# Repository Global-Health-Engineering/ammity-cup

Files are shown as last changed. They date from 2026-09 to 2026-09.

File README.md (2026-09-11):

<!-- badges: start -->



<!-- badges: end -->

<br>
<p align="middle">
Global Health Engineering, ETH Zurich
</p>

# SpaceCup (AMMITY)

- **Kim Keller** (ETH Zürich, Global Health Engineering) *design, construction, testing, writing*
- **Marion Dugué** (ETH Zürich, Global Health Engineering) *flight-experiment co-lead, supervision*
- **Jakub Tkaczuk** [ORCID 0000-0001-7997-9423](https://orcid.org/0000-0001-7997-9423) (ETH Zürich, Global Health Engineering) *supervision, page development & maintenance*
- **Elizabeth Tilley** [ORCID 0000-0002-2095-9724](https://orcid.org/0000-0002-2095-9724) (ETH Zürich, Global Health Engineering) *supervision*

**SpaceCup (AMMITY) is an open-source, cast-silicone menstrual cup that seals before extraction, designed for menstruation in reduced gravity.** Seven closing mechanisms were designed on a shared base cup geometry; six were scored in a 1 G bench test, with Flower Low and Flower High scoring highest at 24 out of 25, and Flower Low, the only fully functional prototype available at the time, was flown during the Asclepios VI parabolic-flight campaign. SpaceCup is a research prototype, bench-tested and flown for short reduced-gravity windows, not a certified medical device.

**Full site, with renders, 3D models and documentation, is available [here](https://global-health-engineering.github.io/ammity-cup/).**

## At a glance

| Characteristic | Description |
| --- | --- |
| Mechanisms designed | 7: Flower Low, Flower High, Twister, Umbrella, Duckbill, Drawstring, Balloon |
| Mechanisms bench-scored | 6 (Balloon excluded, not reliably manufacturable) |
| Best bench score | Flower Low and Flower High, 24/25 |
| Flown | Flower Low, Asclepios VI parabolic-flight campaign |
| Manufacture | Cast silicone in 3D-printed moulds |
| CAD | Siemens NX source, shipped as STEP |
| Status | Research prototype |

## Quick start

1. Pick a variant in [`hardware/README.md`](hardware/README.md).
2. Print its `mould-stl/`.
3. Cast, following [`docs/manufacturing.md`](docs/manufacturing.md).
4. Use and clean, following [`docs/use.md`](docs/use.md).

## Repository layout

```
hardware/              CERN-OHL-P v2: the cup and mould geometry
├── README.md          Variant table, file map, rename map
├── nx.md              Siemens NX source CAD and the STEP editable format
├── flower-low/         Flown mechanism (step/, stl/, mould-stl/)
├── flower-high/        Bench-tested Flower variant
├── twister/             Bench-tested mechanism
├── umbrella/            Bench-tested mechanism
├── duckbill/            Bench-tested mechanism
├── drawstring/          Bench-tested mechanism
├── balloon/             Not reliably manufacturable, not scored
├── extraction-valve/    Untested concept, outside the bench-tested set
└── artificial-vagina/   Test equipment, not a cup design

docs/                  CC BY 4.0: design, manufacturing, use and validation
├── design.md           Base geometry, the seven mechanisms, bench scoring
├── manufacturing.md    Mould printing and silicone casting
├── use.md              Insertion, activation, extraction, cleaning
├── validation.md       Bench-test and parabolic-flight results
├── flight-protocol.md  The Asclepios VI flight test procedure
├── design-history.md   Where the base geometry and mechanisms came from
└── moulding-guide.pdf  The original injection-moulding guide

data/                  CC BY 4.0: bench, cleaning and flight-questionnaire data
tools/                 CC BY 4.0: scripts that regenerate every render and gate CI
site/                  CC BY 4.0: this repository's GitHub Pages site (Astro)
CITATION.cff           Machine-readable citation metadata
```

## Citation

If you use this hardware, please cite it; see [`CITATION.cff`](CITATION.cff) for the machine-readable record:

> SpaceCup (AMMITY): an open-source menstrual cup that seals before
> extraction, for menstruation in reduced gravity. Kim Keller, Marion
> Dugué, Jakub Tkaczuk, Elizabeth Tilley. ETH Zurich, Global Health
> Engineering. Version 1.0.0. https://github.com/Global-Health-Engineering/ammity-cup

## License

Different parts of this repository are released under different licenses, following standard practice for open-hardware projects:

| Component | License |
| --- | --- |
| Hardware design (STEP, whole-part STL, mould STL in [`hardware/`](hardware/)) | [CERN-OHL-P v2](LICENSE-CERN-OHL-P-2.0.md) |
| Documentation, data, site and tooling | [CC BY 4.0](LICENSE-CC-BY-4.0.md) |

## Acknowledgements

The parabolic-flight experiments were flown by the analogue astronauts of the Asclepios VI mission. Medical-grade silicone was donated by WACKER Chemie AG. Medical input was provided by Dr. Cornelia Betschart. The team also thanks CNES for sharing their expertise in human spaceflight and space medicine.

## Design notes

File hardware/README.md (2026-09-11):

# hardware

Licensed **CERN-OHL-P v2** (see `../LICENSE-CERN-OHL-P-2.0.md`).

## Variants

| Variant | Mechanism | Status | Bench score | Folder |
|---|---|---|---|---|
| flower-low | Five flexible petals, each joined by a silicone string to a pull mechanism in the stem, that close together to seal the opening (thesis p.10) | flown (Asclepios VI) | 24/25 | [`flower-low/`](flower-low/) |
| flower-high | The same petal-and-string mechanism as Flower Low, with the petals' base moved closer to the rim for further reach against fluid pooled above the cup (thesis p.10) | bench-tested | 24/25 | [`flower-high/`](flower-high/) |
| twister | A thin membrane skin that forms a hyperboloid seal when the cup's bottom part is rotated against the top (thesis p.10) | bench-tested | 21/25 | [`twister/`](twister/) |
| umbrella | An inverted-umbrella structure that expands into a seal when a central element is pulled downward (thesis p.10) | bench-tested | 16/25 | [`umbrella/`](umbrella/) |
| balloon | An inflatable membrane on the cup wall that rotates upward to seal the opening when a stem-integrated balloon is compressed (thesis p.10) | not reliably manufacturable | not scored (excluded, thesis p.20) | [`balloon/`](balloon/) |
| duckbill | A pressure-difference valve between an upper and lower chamber, opened by squeezing the cup before removal (thesis p.10) | bench-tested | 22/25 | [`duckbill/`](duckbill/) |
| drawstring | A flexible lid, folded against the inner wall, drawn across the opening by a stem-integrated pull string (thesis p.10) | bench-tested | 18/25 | [`drawstring/`](drawstring/) |
| extraction-valve | A valve-and-button assembly intended to withdraw fluid through a port while the cup stays inserted; an eighth, later concept, not one of the thesis's seven mechanisms and not tested or described in the thesis (see [`../docs/design.md`](../docs/design.md)) | untested concept | not scored | [`extraction-valve/`](extraction-valve/) |
| artificial-vagina | Two test models: the self-made model here, cast from the printed mould, was used for the 1 G bench tests (thesis pp.14-15); the flights used a separate, store-bought model, not shipped in this repository (thesis p.17). The file names ("parabolicflight_vagina") are the author's own and predate the flight/bench distinction | test equipment | not applicable | [`artificial-vagina/`](artificial-vagina/) |

Bench scores are the `overall` column of [`../data/ground-test-scores.csv`](../data/ground-test-scores.csv) (out of 25); see [`../docs/design.md`](../docs/design.md) for the full breakdown by criterion.

## What is in each folder

- `step/` holds the cup and mould B-rep, editable.
- `stl/` holds the whole cup and whole mould as single meshes, for viewing; print from `mould-stl/`, which holds the split, print-ready pieces.
- `mould-stl/` holds the print-ready mould pieces, split for printing.

## Which files are the cup and which are the mould

STEP files with `mould` in the name are moulds. The rest are the cast parts. Some cast parts are modelled as halves rather than a single closed solid: `umbrella/menstrual-cup-medium-without-umbrella.step` and `duckbill/duckbill-half-withrim.step`.

## Known gaps

- The balloon membrane exists only as a mould (`balloon-top-mould.step`); the balloon part itself could not be manufactured reliably and was excluded from bench testing (thesis p.20). The concept render shows the balloon derived from that mould's cavity, with the vent and core-pin channels trimmed (`tools/render_parts.py`, `derive_mould_cavity`), not from a part file.
- The drawstring lid is modelled flat, as moulded, not folded against the inner wall as it sits in the cup. The concept render shows it that way: flat, beside the cup.
- `flower-high/step/flower-cup-withrim-higher.step` is one fused solid (cup, petal disc, petals and strings together). The renders colour its petals and strings by a geometric rule calibrated on Flower Low's separate solids (`tools/parts.py`, `FaceSplit`), not by solids in the file.
- `flower-low/step/flower-cup-withrim-part.step` holds 6 solids: two cup-body halves split at the mould parting plane, two small pieces at the stem end, a petal disc, and the petals-with-strings solid.
- `flower-low` also contains a `flower-stopper` (`flower-stopper.step`, `flower-stopper-mould.step`), which the thesis does not describe.
- The extraction valve is an eighth, later concept: it is not one of the thesis's seven designed mechanisms, was not tested, and is not described in the thesis; it has no bench-test or flight data.
- In the Flower Low and Flower High CAD, the pull strings are modelled straight, as cast (the mould cores run to the same length). In the cast cup, each petal's string joins the pull mechanism in the stem (thesis p.10). The renders show this as-cast, straight-string geometry, not the strings pulled taut.
- The drawstring's pull-string tabs are small and sit inside the rim, so they are barely visible in the render.

## Printing the moulds

The moulds print in ASA when the silicone needs a heated, 100 °C cure (medical-grade ELASTOSIL), or in PLA, PETG or ABS for room-temperature-cured silicones such as Smooth-Sil and Rebound. See [`../docs/manufacturing.md`](../docs/manufacturing.md) for material selection, mould features, mixing, injection, curing times and known defects.

## Units

Every STL and STEP file here is in millimetres, checked in CI:

```bash
python3 tools/verify_units.py "hardware/*/mould-stl/*.stl" "hardware/*/stl/*.stl"
```

STEP files declare `SI_UNIT(.MILLI.,.METRE.)` and need no conversion.

## Rename map

The thesis uses the author's original names. This repository renames every shipped file to a consistent, lower-case, hyphenated scheme. The table below is the full old to new mapping.

| Original name (thesis, CAD export) | In this repository |
|---|---|
| `Flower Low Cup/Print Flower/flower_cup_withrim_mold_bottomleft_m.stl` | `flower-low/mould-stl/flower-cup-withrim-mould-bottomleft.stl` |
| `Flower Low Cup/Print Flower/flower_cup_withrim_mold_bottomright_m.stl` | `flower-low/mould-stl/flower-cup-withrim-mould-bottomright.stl` |
| `Flower Low Cup/Print Flower/flower_cup_withrim_mold_middleleft_m.stl` | `flower-low/mould-stl/flower-cup-withrim-mould-middleleft.stl` |
| `Flower Low Cup/Print Flower/flower_cup_withrim_mold_middleright_m.stl` | `flower-low/mould-stl/flower-cup-withrim-mould-middleright.stl` |
| `Flower Low Cup/Print Flower/flower_cup_withrim_mold_topleft_m.stl` | `flower-low/mould-stl/flower-cup-withrim-mould-topleft.stl` |
| `Flower Low Cup/Print Flower/flower_cup_withrim_mold_topright_m.stl` | `flower-low/mould-stl/flower-cup-withrim-mould-topright.stl` |
| `Flower Low Cup/Print Flower/flower_stopper_mold_bottom_m.stl` | `flower-low/mould-stl/flower-stopper-mould-bottom.stl` |
| `Flower Low Cup/Print Flower/flower_stopper_mold_top_m.stl` | `flower-low/mould-stl/flower-stopper-mould-top.stl` |
| `Flower Low Cup/Step files/flower_cup_withrim_mold_m.stp` | `flower-low/step/flower-cup-withrim-mould.step` |
| `Flower Low Cup/Step files/flower_cup_withrim_part_m.stp` | `flower-low/step/flower-cup-withrim-part.step` |
| `Flower Low Cup/Step files/flower_stopper_m.stp` | `flower-low/step/flower-stopper.step` |
| `Flower Low Cup/Step files/flower_stopper_mold_m.stp` | `flower-low/step/flower-stopper-mould.step` |
| `Flower Low Cup/Stl files/flower_cup_withrim_mold_m.stl` | `flower-low/stl/flower-cup-withrim-mould.stl` |
| `Flower Low Cup/Stl files/flower_cup_withrim_part_m.stl` | `flower-low/stl/flower-cup-withrim-part.stl` |
| `Flower Low Cup/Stl files/flower_stopper_m.stl` | `flower-low/stl/flower-stopper.stl` |
| `Flower Low Cup/Stl files/flower_stopper_mold_m.stl` | `flower-low/stl/flower-stopper-mould.stl` |
| `Flower High Cup/Print Flower high/flower_cup_withrim_higher_mold_inleft.stl` | `flower-high/mould-stl/flower-cup-withrim-higher-mould-inleft.stl` |
| `Flower High Cup/Print Flower high/flower_cup_withrim_higher_mold_inright.stl` | `flower-high/mould-stl/flower-cup-withrim-higher-mould-inright.stl` |
| `Flower High Cup/Print Flower high/flower_cup_withrim_higher_mold_outbottomleft.stl` | `flower-high/mould-stl/flower-cup-withrim-higher-mould-outbottomleft.stl` |
| `Flower High Cup/Print Flower high/flower_cup_withrim_higher_mold_outbottomright.stl` | `flower-high/mould-stl/flower-cup-withrim-higher-mould-outbottomright.stl` |
| `Flower High Cup/Print Flower high/flower_cup_withrim_higher_mold_outtopleft.stl` | `flower-high/mould-stl/flower-cup-withrim-higher-mould-outtopleft.stl` |
| `Flower High Cup/Print Flower high/flower_cup_withrim_higher_mold_outtopright.stl` | `flower-high/mould-stl/flower-cup-withrim-higher-mould-outtopright.stl` |
| `Flower High Cup/Step files/flower_cup_withrim_higher_m.stp` | `flower-high/step/flower-cup-withrim-higher.step` |
| `Flower High Cup/Step files/flower_cup_withrim_higher_mold_m.stp` | `flower-high/step/flower-cup-withrim-higher-mould.step` |
| `Flower High Cup/Stl files/flower_cup_withrim_higher_m.stl` | `flower-high/stl/flower-cup-withrim-higher.stl` |
| `Flower High Cup/Stl files/flower_cup_withrim_higher_mold_m.stl` | `flower-high/stl/flower-cup-withrim-higher-mould.stl` |
| `Twister Cup/Print Twister/Twister_Cup_Top2_bottom.stl` | `twister/mould-stl/twister-cup-top2-bottom.stl` |
| `Twister Cup/Print Twister/Twister_Cup_Top2_middle.stl` | `twister/mould-stl/twister-cup-top2-middle.stl` |
| `Twister Cup/Print Twister/Twister_Cup_Top2_middleoutside.stl` | `twister/mould-stl/twister-cup-top2-middleoutside.stl` |
| `Twister Cup/Print Twister/Twister_Cup_Top2_top.stl` | `twister/mould-stl/twister-cup-top2-top.stl` |
| `Twister Cup/Print Twister/twister_cup_bottom_3_withdent_inleft.stl` | `twister/mould-stl/twister-cup-bottom-3-withdent-inleft.stl` |
| `Twister Cup/Print Twister/twister_cup_bottom_3_withdent_inright.stl` | `twister/mould-stl/twister-cup-bottom-3-withdent-inright.stl` |
| `Twister Cup/Print Twister/twister_cup_bottom_3_withdent_outleft.stl` | `twister/mould-stl/twister-cup-bottom-3-withdent-outleft.stl` |
| `Twister Cup/Print Twister/twister_cup_bottom_3_withdent_outright.stl` | `twister/mould-stl/twister-cup-bottom-3-withdent-outright.stl` |
| `Twister Cup/Print Twister/twister_skin_mold_1.stl` | `twister/mould-stl/twister-skin-mould-1.stl` |
| `Twister Cup/Print Twister/twister_skin_mold_2.stl` | `twister/mould-stl/twister-skin-mould-2.stl` |
| `Twister Cup/Print Twister/twister_skin_mold_3.stl` | `twister/mould-stl/twister-skin-mould-3.stl` |
| `Twister Cup/Print Twister/twister_skin_mold_4.stl` | `twister/mould-stl/twister-skin-mould-4.stl` |
| `Twister Cup/Print Twister/twister_skin_mold_5.stl` | `twister/mould-stl/twister-skin-mould-5.stl` |
| `Twister Cup/Print Twister/twister_skin_mold_6.stl` | `twister/mould-stl/twister-skin-mould-6.stl` |
| `Twister Cup/Print Twister/twister_skin_mold_insideleft.stl` | `twister/mould-stl/twister-skin-mould-insideleft.stl` |
| `Twister Cup/Print Twister/twister_skin_mold_insideright.stl` | `twister/mould-stl/twister-skin-mould-insideright.stl` |
| `Twister Cup/Step files/Twister_Cup_Top_m.stp` | `twister/step/twister-cup-top.step` |
| `Twister Cup/Step files/Twister_Cup_Top_mold.stp` | `twister/step/twister-cup-top-mould.step` |
| `Twister Cup/Step files/twister_cup_bottom_withdent.stp` | `twister/step/twister-cup-bottom-withdent.step` |
| `Twister Cup/Step files/twister_cup_bottom_withdent_mold.stp` | `twister/step/twister-cup-bottom-withdent-mould.step` |
| `Twister Cup/Step files/twister_skin.stp` | `twister/step/twister-skin.step` |
| `Twister Cup/Step files/twister_skin_mold.stp` | `twister/step/twister-skin-mould.step` |
| `Twister Cup/Stl files/Twister_Cup_Top_m.stl` | `twister/stl/twister-cup-top.stl` |
| `Twister Cup/Stl files/Twister_Cup_Top_mold.stl` | `twister/stl/twister-cup-top-mould.stl` |
| `Twister Cup/Stl files/twister_cup_bottom_withdent.stl` | `twister/stl/twister-cup-bottom-withdent.stl` |
| `Twister Cup/Stl files/twister_cup_bottom_withdent_mold.stl` | `twister/stl/twister-cup-bottom-withdent-mould.stl` |
| `Twister Cup/Stl files/twister_skin.stl` | `twister/stl/twister-skin.stl` |
| `Twister Cup/Stl files/twister_skin_mold.stl` | `twister/stl/twister-skin-mould.stl` |
| `Umbrella Cup/Print Umbrella/menstrual_cup_medium_without_umbrella_mold_insideleft.stl` | `umbrella/mould-stl/menstrual-cup-medium-without-umbrella-mould-insideleft.stl` |
| `Umbrella Cup/Print Umbrella/menstrual_cup_medium_without_umbrella_mold_insideright.stl` | `umbrella/mould-stl/menstrual-cup-medium-without-umbrella-mould-insideright.stl` |
| `Umbrella Cup/Print Umbrella/menstrual_cup_medium_without_umbrella_mold_outsideleft_m.stl` | `umbrella/mould-stl/menstrual-cup-medium-without-umbrella-mould-outsideleft.stl` |
| `Umbrella Cup/Print Umbrella/menstrual_cup_medium_without_umbrella_mold_outsideright_m.stl` | `umbrella/mould-stl/menstrual-cup-medium-without-umbrella-mould-outsideright.stl` |
| `Umbrella Cup/Print Umbrella/umbrella_contain_silicone_mold_inside.stl` | `umbrella/mould-stl/umbrella-contain-silicone-mould-inside.stl` |
| `Umbrella Cup/Print Umbrella/umbrella_contain_silicone_mold_outsideleft.stl` | `umbrella/mould-stl/umbrella-contain-silicone-mould-outsideleft.stl` |
| `Umbrella Cup/Print Umbrella/umbrella_contain_silicone_mold_outsideright.stl` | `umbrella/mould-stl/umbrella-contain-silicone-mould-outsideright.stl` |
| `Umbrella Cup/Print Umbrella/umbrella_top_2_open_Full_mold_top_m.stl` | `umbrella/mould-stl/umbrella-top-2-open-full-mould-top.stl` |
| `Umbrella Cup/Print Umbrella/umbrella_top_2_open_Full_mold_u1_m.stl` | `umbrella/mould-stl/umbrella-top-2-open-full-mould-u1.stl` |
| `Umbrella Cup/Print Umbrella/umbrella_top_2_open_Full_mold_u2_m.stl` | `umbrella/mould-stl/umbrella-top-2-open-full-mould-u2.stl` |
| `Umbrella Cup/Print Umbrella/umbrella_top_2_open_Full_mold_u3_m.stl` | `umbrella/mould-stl/umbrella-top-2-open-full-mould-u3.stl` |
| `Umbrella Cup/Print Umbrella/umbrella_top_2_open_Full_mold_u4_m.stl` | `umbrella/mould-stl/umbrella-top-2-open-full-mould-u4.stl` |
| `Umbrella Cup/Step files/menstrual_cup_medium_without_umbrella_m.stp` | `umbrella/step/menstrual-cup-medium-without-umbrella.step` |
| `Umbrella Cup/Step files/menstrual_cup_medium_without_umbrella_mold_m.stp` | `umbrella/step/menstrual-cup-medium-without-umbrella-mould.step` |
| `Umbrella Cup/Step files/umbrella_contain_silicone.stp` | `umbrella/step/umbrella-contain-silicone.step` |
| `Umbrella Cup/Step files/umbrella_contain_silicone_mold.stp` | `umbrella/step/umbrella-contain-silicone-mould.step` |
| `Umbrella Cup/Step files/umbrella_top_open_Full_m.stp` | `umbrella/step/umbrella-top-open-full.step` |
| `Umbrella Cup/Step files/umbrella_top_open_Full_mold_m.stp` | `umbrella/step/umbrella-top-open-full-mould.step` |
| `Umbrella Cup/Step files/umbrella_top_open_Full_wings_mold.stp` | `umbrella/step/umbrella-top-open-full-wings-mould.step` |
| `Umbrella Cup/Stl files/menstrual_cup_medium_without_umbrella_m.stl` | `umbrella/stl/menstrual-cup-medium-without-umbrella.stl` |
| `Umbrella Cup/Stl files/menstrual_cup_medium_without_umbrella_mold_m.stl` | `umbrella/stl/menstrual-cup-medium-without-umbrella-mould.stl` |
| `Umbrella Cup/Stl files/umbrella_contain_silicone.stl` | `umbrella/stl/umbrella-contain-silicone.stl` |
| `Umbrella Cup/Stl files/umbrella_contain_silicone_mold.stl` | `umbrella/stl/umbrella-contain-silicone-mould.stl` |
| `Umbrella Cup/Stl files/umbrella_top_open_Full_m.stl` | `umbrella/stl/umbrella-top-open-full.stl` |
| `Umbrella Cup/Stl files/umbrella_top_open_Full_mold_m.stl` | `umbrella/stl/umbrella-top-open-full-mould.stl` |
| `Umbrella Cup/Stl files/umbrella_top_open_Full_wings_mold.stl` | `umbrella/stl/umbrella-top-open-full-wings-mould.stl` |
| `Drawstring Cup/Stl files/Drawsting.stl` | `drawstring/stl/drawstring.stl` |
| `Drawstring Cup/Stl files/Drawsting_mold.stl` | `drawstring/stl/drawstring-mould.stl` |
| `Drawstring Cup/Print Drawstring/Drawsting2_mold_bottom.stl` | `drawstring/mould-stl/drawstring2-mould-bottom.stl` |
| `Drawstring Cup/Print Drawstring/Drawsting2_mold_top.stl` | `drawstring/mould-stl/drawstring2-mould-top.stl` |
| `Drawstring Cup/Print Drawstring/menstrual_cup_medium_drawstring5_inbottomleft.stl` | `drawstring/mould-stl/menstrual-cup-medium-drawstring5-inbottomleft.stl` |
| `Drawstring Cup/Print Drawstring/menstrual_cup_medium_drawstring5_inbottomright.stl` | `drawstring/mould-stl/menstrual-cup-medium-drawstring5-inbottomright.stl` |
| `Drawstring Cup/Print Drawstring/menstrual_cup_medium_drawstring5_inmiddle.stl` | `drawstring/mould-stl/menstrual-cup-medium-drawstring5-inmiddle.stl` |
| `Drawstring Cup/Print Drawstring/menstrual_cup_medium_drawstring5_intopleft.stl` | `drawstring/mould-stl/menstrual-cup-medium-drawstring5-intopleft.stl` |
| `Drawstring Cup/Print Drawstring/menstrual_cup_medium_drawstring5_intopright.stl` | `drawstring/mould-stl/menstrual-cup-medium-drawstring5-intopright.stl` |
| `Drawstring Cup/Print Drawstring/menstrual_cup_medium_drawstring5_outleft.stl` | `drawstring/mould-stl/menstrual-cup-medium-drawstring5-outleft.stl` |
| `Drawstring Cup/Print Drawstring/menstrual_cup_medium_drawstring5_outright.stl` | `drawstring/mould-stl/menstrual-cup-medium-drawstring5-outright.stl` |
| `Drawstring Cup/Step files/Drawsting.stp` | `drawstring/step/drawstring.step` |
| `Drawstring Cup/Step files/Drawsting_mold.stp` | `drawstring/step/drawstring-mould.step` |
| `Drawstring Cup/Step files/menstrual_cup_medium_drawstring.stp` | `drawstring/step/menstrual-cup-medium-drawstring.step` |
| `Drawstring Cup/Step files/menstrual_cup_medium_drawstring_mold.stp` | `drawstring/step/menstrual-cup-medium-drawstring-mould.step` |
| `Drawstring Cup/Stl files/menstrual_cup_medium_drawstring.stl` | `drawstring/stl/menstrual-cup-medium-drawstring.stl` |
| `Drawstring Cup/Stl files/menstrual_cup_medium_drawstring_mold.stl` | `drawstring/stl/menstrual-cup-medium-drawstring-mould.stl` |
| `Duckbill Cup/Print Duckbill/duckbill2_half_withrim_insidebottom.stl` | `duckbill/mould-stl/duckbill2-half-withrim-insidebottom.stl` |
| `Duckbill Cup/Print Duckbill/duckbill2_half_withrim_insidetop.stl` | `duckbill/mould-stl/duckbill2-half-withrim-insidetop.stl` |
| `Duckbill Cup/Print Duckbill/duckbill2_half_withrim_outsideleft.stl` | `duckbill/mould-stl/duckbill2-half-withrim-outsideleft.stl` |
| `Duckbill Cup/Print Duckbill/duckbill2_half_withrim_outsideright.stl` | `duckbill/mould-stl/duckbill2-half-withrim-outsideright.stl` |
| `Duckbill Cup/Step files/duckbill_half_withrim.stp` | `duckbill/step/duckbill-half-withrim.step` |
| `Duckbill Cup/Step files/duckbill_half_withrim_mold.stp` | `duckbill/step/duckbill-half-withrim-mould.step` |
| `Duckbill Cup/Stl files/duckbill_half_withrim.stl` | `duckbill/stl/duckbill-half-withrim.stl` |
| `Duckbill Cup/Stl files/duckbill_half_withrim_mold.stl` | `duckbill/stl/duckbill-half-withrim-mould.stl` |
| `Balloon Cup/Stl files/Balloon_Top_mold.stl` | `balloon/stl/balloon-top-mould.stl` |
| `Balloon Cup/Print Balloon (with pipe)/Balloon_Top_1_Mold1_outsideleft.stl` | `balloon/mould-stl/balloon-top-1-mould1-outsideleft.stl` |
| `Balloon Cup/Print Balloon (with pipe)/Balloon_Top_1_Mold1_outsideright.stl` | `balloon/mould-stl/balloon-top-1-mould1-outsideright.stl` |
| `Balloon Cup/Print Balloon (with pipe)/Balloon_Top_2_Mold_insideleft.stl` | `balloon/mould-stl/balloon-top-2-mould-insideleft.stl` |
| `Balloon Cup/Print Balloon (with pipe)/Balloon_Top_2_Mold_insidemiddle.stl` | `balloon/mould-stl/balloon-top-2-mould-insidemiddle.stl` |
| `Balloon Cup/Print Balloon (with pipe)/Balloon_Top_2_Mold_insideright.stl` | `balloon/mould-stl/balloon-top-2-mould-insideright.stl` |
| `Balloon Cup/Print Balloon (with pipe)/balloon_pipe1_mold_inside.stl` | `balloon/mould-stl/balloon-pipe1-mould-inside.stl` |
| `Balloon Cup/Print Balloon (with pipe)/balloon_pipe1_mold_outsideleft.stl` | `balloon/mould-stl/balloon-pipe1-mould-outsideleft.stl` |
| `Balloon Cup/Print Balloon (with pipe)/balloon_pipe1_mold_outsideright.stl` | `balloon/mould-stl/balloon-pipe1-mould-outsideright.stl` |
| `Balloon Cup/Print Balloon (with pipe)/menstrual_cup_medium_without_balloon_mold_inbottomleft.stl` | `balloon/mould-stl/menstrual-cup-medium-without-balloon-mould-inbottomleft.stl` |
| `Balloon Cup/Print Balloon (with pipe)/menstrual_cup_medium_without_balloon_mold_inbottomright.stl` | `balloon/mould-stl/menstrual-cup-medium-without-balloon-mould-inbottomright.stl` |
| `Balloon Cup/Print Balloon (with pipe)/menstrual_cup_medium_without_balloon_mold_intopleft.stl` | `balloon/mould-stl/menstrual-cup-medium-without-balloon-mould-intopleft.stl` |
| `Balloon Cup/Print Balloon (with pipe)/menstrual_cup_medium_without_balloon_mold_intopright.stl` | `balloon/mould-stl/menstrual-cup-medium-without-balloon-mould-intopright.stl` |
| `Balloon Cup/Print Balloon (with pipe)/menstrual_cup_medium_without_balloon_mold_ousideleft.stl` | `balloon/mould-stl/menstrual-cup-medium-without-balloon-mould-outsideleft.stl` |
| `Balloon Cup/Print Balloon (with pipe)/menstrual_cup_medium_without_balloon_mold_outsideright.stl` | `balloon/mould-stl/menstrual-cup-medium-without-balloon-mould-outsideright.stl` |
| `Balloon Cup/Step files/Balloon_Top_mold.stp` | `balloon/step/balloon-top-mould.step` |
| `Balloon Cup/Step files/balloon_pipe.stp` | `balloon/step/balloon-pipe.step` |
| `Balloon Cup/Step files/balloon_pipe_mold.stp` | `balloon/step/balloon-pipe-mould.step` |
| `Balloon Cup/Step files/menstrual_cup_medium_without_balloon.stp` | `balloon/step/menstrual-cup-medium-without-balloon.step` |
| `Balloon Cup/Step files/menstrual_cup_medium_without_balloon_mold.stp` | `balloon/step/menstrual-cup-medium-without-balloon-mould.step` |
| `Balloon Cup/Stl files/balloon_pipe.stl` | `balloon/stl/balloon-pipe.stl` |
| `Balloon Cup/Stl files/balloon_pipe_mold.stl` | `balloon/stl/balloon-pipe-mould.stl` |
| `Balloon Cup/Stl files/menstrual_cup_medium_without_balloon.stl` | `balloon/stl/menstrual-cup-medium-without-balloon.stl` |
| `Balloon Cup/Stl files/menstrual_cup_medium_without_balloon_mold.stl` | `balloon/stl/menstrual-cup-medium-without-balloon-mould.stl` |
| `Extraction Valve/Print valve and button/cup_valve_button_left2.stl` | `extraction-valve/mould-stl/cup-valve-button-left2.stl` |
| `Extraction Valve/Print valve and button/cup_valve_button_right2.stl` | `extraction-valve/mould-stl/cup-valve-button-right2.stl` |
| `Extraction Valve/Print valve and button/menstrual_cup_valve_inside.stl` | `extraction-valve/mould-stl/menstrual-cup-valve-inside.stl` |
| `Extraction Valve/Print valve and button/menstrual_cup_valve_outleft.stl` | `extraction-valve/mould-stl/menstrual-cup-valve-outleft.stl` |
| `Extraction Valve/Print valve and button/menstrual_cup_valve_outright.stl` | `extraction-valve/mould-stl/menstrual-cup-valve-outright.stl` |
| `Extraction Valve/Step files/cup_valve_button.stp` | `extraction-valve/step/cup-valve-button.step` |
| `Extraction Valve/Step files/cup_valve_button_mold.stp` | `extraction-valve/step/cup-valve-button-mould.step` |
| `Extraction Valve/Step files/menstrual_cup_valve.stp` | `extraction-valve/step/menstrual-cup-valve.step` |
| `Extraction Valve/Step files/menstrual_cup_valve_mold.stp` | `extraction-valve/step/menstrual-cup-valve-mould.step` |
| `Extraction Valve/Stl files/cup_valve_button.stl` | `extraction-valve/stl/cup-valve-button.stl` |
| `Extraction Valve/Stl files/cup_valve_button_mold.stl` | `extraction-valve/stl/cup-valve-button-mould.stl` |
| `Extraction Valve/Stl files/menstrual_cup_valve.stl` | `extraction-valve/stl/menstrual-cup-valve.stl` |
| `Extraction Valve/Stl files/menstrual_cup_valve_mold.stl` | `extraction-valve/stl/menstrual-cup-valve-mould.stl` |
| `Artificial Vagina/Print Vagina/parabolicflight_vagina2_inleft.stl` | `artificial-vagina/mould-stl/parabolicflight-vagina2-inleft.stl` |
| `Artificial Vagina/Print Vagina/parabolicflight_vagina2_inright.stl` | `artificial-vagina/mould-stl/parabolicflight-vagina2-inright.stl` |
| `Artificial Vagina/Print Vagina/parabolicflight_vagina2_outsideleft.stl` | `artificial-vagina/mould-stl/parabolicflight-vagina2-outsideleft.stl` |
| `Artificial Vagina/Print Vagina/parabolicflight_vagina2_outsideright.stl` | `artificial-vagina/mould-stl/parabolicflight-vagina2-outsideright.stl` |
| `Artificial Vagina/Step files/parabolicflight_vagina.stp` | `artificial-vagina/step/parabolicflight-vagina.step` |
| `Artificial Vagina/Step files/parabolicflight_vagina_mold.stp` | `artificial-vagina/step/parabolicflight-vagina-mould.step` |
| `Artificial Vagina/Stl files/parabolicflight_vagina.stl` | `artificial-vagina/stl/parabolicflight-vagina.stl` |
| `Artificial Vagina/Stl files/parabolicflight_vagina_mold.stl` | `artificial-vagina/stl/parabolicflight-vagina-mould.stl` |

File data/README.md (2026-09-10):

# data

Bench-test scores, cleaning-assessment colony counts, and anonymised parabolic-flight questionnaire results for the SpaceCup menstrual cup. Every column of every file is documented in [`codebook.csv`](codebook.csv).

## Files

| File | Contents |
| --- | --- |
| `ground-test-scores.csv` | Functional bench-test scores for 6 prototypes across 5 criteria (6 rows) |
| `cleaning-colony-counts.csv`  | Post-cleaning agar-plate colony counts for 3 methods x 5 cups (15 rows)  |
| `flight-questionnaire.csv` | Anonymised post-flight questionnaire results for 3 participants (3 rows) |
| `codebook.csv` | One row per column of every file above: name, type, observed values, description, unit |

## Provenance

All values were transcribed by hand from the author's MSc thesis (Keller, 2026, not published with this repository):

- `ground-test-scores.csv`: Table 2, p.20.
- `cleaning-colony-counts.csv`: Table 3, p.23.
- `flight-questionnaire.csv`: the three post-flight questionnaires completed by the parabolic-flight test participants.

## Anonymisation

Questionnaire participants are identified only as P1-P3. Free-text answers are summarised into the `notes` column in paraphrase, never quoted verbatim, and never name a participant. The original completed questionnaire forms are not published in this repository.

## Headline results

- Both Flower designs (petal bases low in the cup, and nearer the rim) scored 24/25 in the functional bench test, the highest of any prototype.
- 70 % isopropanol (`ipa-70`) gave the lowest total colony counts of the three cleaning methods, i.e. the best disinfection performance.
- No fluid volumes were measured during the parabolic-flight tests; the flight results are qualitative observations only.

## Flight results are qualitative

The parabolic-flight tests provided a first, qualitative evaluation of the Flower mechanism under reduced gravity. The small test-fluid volume and the limited transparency of the artificial-vagina model prevented reliable quantitative measurement of fluid containment, so no volumes were recorded (thesis p.22).

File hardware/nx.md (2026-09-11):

# Source CAD (Siemens NX)

The design was modelled in **Siemens NX 2406**. The shipped STEP files were exported from **NX 2406.3002 on 2026-09-08**; both facts are recorded in the STEP file headers themselves, for example:

```
FILE_NAME(
/* time_stamp */ '2026-09-08T16:13:29+02:00',
/* originating_system */ 'SIEMENS PLM Software NX2406.3002',
```

## No native NX files in this repository

The native NX part files (`.prt`) are not published here: they embed local file-system paths from the author's machine. STEP is the only editable format this repository ships.

## The editable format

STEP (AP214, millimetres) is the editable format and opens in any B-rep CAD tool, for example **NX**, **FreeCAD**, **Onshape** or **Fusion**. The shipped STEP files declare `SI_UNIT(.MILLI.,.METRE.)`; a re-export that does not set millimetres explicitly can silently change the scale.

## Regenerating the renders

The renders under `site/public/renders/` are generated from the STEP files, not from NX, by [`../tools/README.md`](../tools/README.md)'s `step_to_mesh.py` (converts each STEP file to a mesh) and `render_parts.py` (renders the meshes to the images used on the site).

Each script documents its own run command and requirements in its module docstring.

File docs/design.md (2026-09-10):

# Design

Engineering reference for the SpaceCup base geometry, the seven mechanisms designed in the thesis, and the bench-test scoring behind six of them. Numbers here are transcribed from Keller, K. (2026). *AMMITY*. MSc thesis, ETH Zurich, Global Health Engineering. Not published with this repository. Page references are given as `(thesis p.N)`.

## Base cup requirements

All seven mechanisms share the same base cup geometry, taken from the 2025 BSc thesis that preceded this project (thesis p.9; see [`design-history.md`](design-history.md)).

| Parameter | Value |
|---|---|
| Wall thickness | 2 mm (+/- 0.3 mm) |
| Pull-out stem | at least 15 mm |
| Size | medium, for adult menstruators |
| Rim outer diameter | 41 to 44 mm |
| Length, excluding stem | 45 to 55 mm |
| Capture volume | 20 to 30 mL |
| Air holes | 2 |
| Operation | one-handed, two-finger |

(thesis p.9)

## Mechanisms

Seven mechanisms were designed on the base cup and are documented in the thesis (thesis pp.10-11): Flower Low, Flower High, Twister, Umbrella, Balloon, Duckbill and Drawstring. Six were bench-scored; the balloon could not be manufactured reliably and was excluded from scoring (thesis p.20). Only Flower Low was flown, in reduced-gravity flights (thesis pp.17, 20-21). The extraction valve is an eighth, later concept: designed but not tested, and not part of the thesis; it is documented separately below. Bench scores are the `overall` column of [`../data/ground-test-scores.csv`](../data/ground-test-scores.csv), out of 25.

### Flower Low

Five flexible petals close over the opening, each joined by a silicone string to a pull mechanism integrated into the stem; pulling the strings closes the petals and seals the cup (thesis p.10). Bench score 24/25: sealing 4/5 (minor leakage under extreme handling), containment 18 mL, structural reliability 5/5, usability 5/5, manufacturing 5/5. Its only limitation was minor sealing leakage under extreme handling (thesis pp.20-21). Flower Low was the only prototype flown in reduced gravity; see [`validation.md`](validation.md). Folder: [`../hardware/flower-low/`](../hardware/flower-low/).

### Flower High

The same petal-and-string mechanism as Flower Low, with the petals' base moved closer to the rim for further reach against fluid that pools above the cup before entering it (thesis p.10). Bench score 24/25: sealing 5/5, containment 30 mL, structural reliability 5/5, usability 4/5, manufacturing 5/5. Its main limitation was usability: minor friction during insertion into the artificial vagina (thesis pp.20-21). Folder: [`../hardware/flower-high/`](../hardware/flower-high/).

### Twister

A thin membrane skin, fused to the cup's top and bottom parts, closes into a hyperboloid seal when the bottom part is rotated relative to the top (thesis p.10). Bench score 21/25: sealing 5/5, containment 15 mL, structural reliability 5/5, usability 2/5, manufacturing 4/5. Its main limitation was usability: as the cup is removed, the upper and lower sections pull apart, untwisting the mechanism and reopening the cup (thesis pp.20-21). Folder: [`../hardware/twister/`](../hardware/twister/).

### Umbrella

An inverted-umbrella structure expands into a seal when a central element is pulled downward (thesis p.10). Bench score 16/25: sealing 4/5, containment 22 mL, structural reliability 1/5, usability 3/5, manufacturing 3/5. Its main limitation was structural reliability: the thin umbrella structure failed within the first few activations, after which it could no longer close the cup (thesis pp.20-21). Folder: [`../hardware/umbrella/`](../hardware/umbrella/).

### Balloon

An inflatable membrane attached to the inner wall of the cup rotates upward, to approximately 90 degrees, and seals the opening when a second, stem-integrated balloon is compressed (thesis p.10). The balloon's thin membrane structures could not be manufactured reliably and it was excluded from bench testing (thesis p.20). Folder: [`../hardware/balloon/`](../hardware/balloon/).

### Duckbill

A pressure-difference valve between an upper and a lower chamber opens when the cup is squeezed before removal, transferring fluid to the lower chamber for containment (thesis p.10). Bench score 22/25: sealing 3/5, containment 14 mL, structural reliability 5/5, usability 5/5, manufacturing 4/5. Its main limitation was sealing performance: leakage under moderate disturbance, because the mechanism opens whenever the cup is squeezed (thesis pp.20-21). Folder: [`../hardware/duckbill/`](../hardware/duckbill/).

### Drawstring

A flexible circular lid, folded in half against the inner wall of the cup, is connected to a pull string in the stem; pulling the string draws the lid across the opening, unfolding it to seal the cup (thesis p.10). Bench score 18/25: sealing 1/5, containment 27 mL, structural reliability 5/5, usability 4/5, manufacturing 3/5. Its main limitation was sealing performance, the lowest possible score: the lid's position was too high to close adequately, letting fluid leak out (thesis pp.20-21). Folder: [`../hardware/drawstring/`](../hardware/drawstring/).

### Extraction valve

An eighth, later concept: not one of the thesis's seven designed mechanisms, and not tested or described in the thesis. The thesis discusses a cup with a syringe or extraction port, letting fluid be removed while the cup stays inserted, as a fundamentally different collection principle worth comparing against the closing-cup approach in future work (thesis p.28; see [`design-history.md`](design-history.md)). The files under [`../hardware/extraction-valve/`](../hardware/extraction-valve/) are an untested concept: they have no bench-test or flight data.

## Scoring

Each bench-tested mechanism was scored on 5 criteria, each on a 1 (not met) to 5 (fully met) scale (thesis Table 1, p.16):

| Criterion | 1 (not met) | 5 (fully met) |
|---|---|---|
| Sealing performance | Immediate, uncontrolled leakage | No leakage observed under any conditions |
| Fluid containment | Well below the 12 mL target volume | Meets or exceeds the 12 mL target volume |
| Structural reliability | Mechanism failed or cracked within the first few activations | No cracks, deformation, or failure after 30 cycles |
| Usability | Insertion, extraction, or reset could not be completed | Full cycle completed easily and intuitively |
| Manufacturability | Could not be fabricated with available methods or materials | Fabricated reliably and consistently with no notable issues |

(thesis Table 1, p.16)

Full score table, from [`../data/ground-test-scores.csv`](../data/ground-test-scores.csv):

| Variant | Sealing | Fluid containment | Containment (mL) | Structural reliability | Usability | Manufacturing | Overall |
|---|---|---|---|---|---|---|---|
| flower-low | 4 | 5 | 18 | 5 | 5 | 5 | 24 |
| flower-high | 5 | 5 | 30 | 5 | 4 | 5 | 24 |
| drawstring | 1 | 5 | 27 | 5 | 4 | 3 | 18 |
| twister | 5 | 5 | 15 | 5 | 2 | 4 | 21 |
| umbrella | 4 | 5 | 22 | 1 | 3 | 3 | 16 |
| duckbill | 3 | 5 | 14 | 5 | 5 | 4 | 22 |

The balloon concept is absent from this table because it could not be manufactured reliably (thesis Table 2, p.20; see [`../data/README.md`](../data/README.md)).

## Why the Flower designs

The functional evaluation identified the two Flower concepts as the most promising designs: both performed well enough, despite room for improvement in sealing and usability, to justify continued development and reduced-gravity testing, while the alternative mechanisms showed more fundamental limitations (thesis p.26). The Flower mechanism is described as the most mature design investigated in the thesis, and its successful operation during the initial reduced-gravity experiments is given as the justification for further development, with future work pursuing two directions: simplifying the Flower for cleanability, manufacturability and operation with medical-grade silicone, and evaluating both Flower Low and Flower High under longer, more representative reduced-gravity conditions (thesis p.30). See [`design-history.md`](design-history.md) for the fuller future-work list.

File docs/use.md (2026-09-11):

# Use (Flower designs)

How the SpaceCup prototypes were used during bench and flight testing. This describes the tested procedure, not a fitting or medical instruction: see the disclaimer at the end.

The steps below apply to the two Flower designs (Flower Low, flown, and Flower High), whose pull strings close the petals; the other mechanisms are operated differently and were not taken this far.

## Insertion

Fold the cup, for example into a C shape, to narrow it for insertion, then release it once past the vaginal opening so it can spring back open.

## Activation

For the Flower mechanisms, activation means pulling the strings that run from the petals to the pull mechanism in the stem, closing the petals over the opening to seal the cup (thesis p.10). The pull should be firm enough to close the mechanism, but not so hard that it extracts the cup along with the strings: an early flight attempt did exactly that, drawing the whole cup out on the first pull before later attempts closed it in place without extracting it (`data/flight-questionnaire.csv`).

## Extraction

Extraction follows activation: once the mechanism is closed and the fluid sealed in, the cup is drawn out by the stem. The bench evaluation, run under lab conditions, scored insertion, extraction and resetting together as usability, joint highest for Flower Low (with the Duckbill) (thesis pp.20-21); in reduced gravity, analogue-astronaut testers reported that both insertion and extraction were generally easy to perform (thesis p.22; see [`validation.md`](validation.md)).

## Resetting the Flower

To reuse a Flower cup, the tail (the pull mechanism in the stem) has to be pushed back to its open, unactivated position after each activation. One flight participant reported this reset as requiring some force (`data/flight-questionnaire.csv`).

## Emptying by syringe

The usability protocol inserted each prototype into the artificial vagina, filled it with artificial menstrual fluid, extracted it, removed the fluid with a syringe, cleaned the cup, and reset the closing mechanism for the next cycle (thesis p.15).

## Cleaning

Three cleaning methods were tested and compared against a reference cup, with colony counts in [`../data/cleaning-colony-counts.csv`](../data/cleaning-colony-counts.csv):

- **70 % isopropanol (IPA)**, wiped then immersed and shaken: the lowest, most consistent colony counts of the three methods, the best disinfection performance tested. Shaking in a confined container likely helped the disinfectant reach narrow gaps and cavities (thesis p.23, p.26).
- **Microwave**, wiped then 30 s upside-down in 20 mL of water in a microwave: performed well for the simpler-geometry Drawstring and Twister designs, but gave noticeably higher colony counts on the Flower designs.
- **Boiling**, 5 min, wiped but not rinsed beforehand: the reference method, but with variable results, likely because residue trapped in cavities was not rinsed away before boiling (thesis p.23).

Geometry matters as much as method: the Flower designs' closely spaced strings and narrow gaps held residue that was harder to reach with steam or boiling water, even though the same gaps were reachable when the cup was shaken in isopropanol (thesis p.23, p.26).

The cleaning assessment was carried out under non-sterile laboratory conditions: cups were contaminated with a standardised load of live-culture yoghurt and then handled with clean, but non-sterile, hands before cleaning and culture on agar plates (thesis pp.18-24). Results are therefore a comparison between designs and procedures, not a validated clinical disinfection protocol.

## Statement

The SpaceCup is a research prototype, tested on the bench and in short parabolic-flight windows. It is not a certified medical device, and it is not for personal use.

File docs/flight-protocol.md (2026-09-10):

# Flight protocol

The parabolic-flight test procedure for the Flower Low SpaceCup, flown during the Asclepios VI mission's parabolic-flight campaign. Rewritten from the mission's dress-rehearsal training slides and from Keller, K. (2026). *AMMITY*. MSc thesis, ETH Zurich, Global Health Engineering. Not published with this repository. Principal investigators: Kim Keller and Marion Dugué.

## 1. Purpose

To perform a first, qualitative test of the Flower mechanism's insertion, activation and extraction in reduced gravity, and to observe the behaviour of a menstrual-fluid analogue in and around the SpaceCup and a commercial tampon for comparison.

## 2. Equipment

- 1 glovebox, to contain the test fluid and prevent any free-floating liquid in the cabin.
- 1 GoPro, to record the procedure.
- 2 SpaceCups (Flower Low).
- 2 tampons.
- 2 artificial vaginas (AV1 and AV2).
- Syringes: 4 small (20 mL) and 1 large (60 mL).
- The test fluid, prepared no more than 2 days before the flight and refrigerated until use.

## 3. The fluid recipe

Egg white 30 mL, ketchup 50 mL, sucrose solution (30 % sugar in water) 20 mL. Ketchup gives the base viscosity and shear-thinning behaviour, egg white gives a clot-like texture, and the sucrose solution adjusts the density; the mixture was stirred gently after combining the ingredients and kept a slightly clot-like texture (thesis p.15).

## 4. Sequence over 6 parabolas

Four small-syringe injections of 6 mL each, plus a final large-syringe injection of 42 mL, for 66 mL of test fluid in total across the flight:

1. **First parabola:** get adjusted to the flight phases. In the horizontal phase, inject 6 mL of test fluid into AV1.
2. **Second parabola:** in reduced gravity, close SpaceCup 1. In the horizontal phase, extract SpaceCup 1, store it in a ziplock bag, insert SpaceCup 2 into AV1, and inject a further 6 mL into AV1.
3. **Third parabola:** in reduced gravity, close SpaceCup 2. In the horizontal phase, extract SpaceCup 2, store it, set AV1 aside, take AV2 in hand, and inject 6 mL into AV2.
4. **Fourth parabola:** in reduced gravity, extract tampon 1 (from AV2). In the horizontal phase, store tampon 1, insert tampon 2 into AV2, and inject 6 mL into AV2.
5. **Fifth parabola:** in reduced gravity, extract tampon 2. In the horizontal phase, store tampon 2, and take up the large syringe (42 mL).
6. **Sixth parabola:** in reduced gravity, inject 42 mL into AV2 (a near-complete cycle) and observe fluid behaviour and flow dynamics. In the horizontal phase, seal both artificial vaginas in ziplock bags.

Closing the SpaceCup happens during the reduced-gravity phase of a parabola; extracting it happens once the aircraft has returned to level, horizontal flight.

**Reduced-gravity window:** the thesis reports approximately 6 seconds of reduced gravity per parabola (thesis p.17); the mission's own dress-rehearsal training material gives approximately 10 seconds as the time constraint to plan around. Both figures are given here because the two sources disagree.

## 5. Roles and timing

One trained operator performed the procedure inside the glovebox for a given run, with a second trained operator ready to take over if the first became disoriented or experienced motion sickness. The GoPro recorded throughout. The procedure was trained and rehearsed on the ground beforehand, with key steps prioritised and non-critical actions skipped if a parabola's reduced-gravity window ran short.

## 6. Observations to record

Fluid movement and behaviour in reduced gravity, containment within the cup, and the performance of the sealing mechanism during activation and extraction; the same observations were recorded for the tampon runs as a comparison. Analogue astronauts also completed a post-flight questionnaire, summarised in [`validation.md`](validation.md) and [`../data/flight-questionnaire.csv`](../data/flight-questionnaire.csv).

A photo of the glovebox setup is a supplied photo, to come.

## 7. Lessons from the flights

From the thesis's discussion of the flight results (thesis p.22) and from the questionnaire notes ([`../data/flight-questionnaire.csv`](../data/flight-questionnaire.csv)):

- Glove sizes: gloves were reported too large for secure handling of the small parts.
- The fluid volume used was too small to reliably compare fluid behaviour or containment between the SpaceCup and the tampon.
- One artificial vagina leaked before its parabola began, so containment and fluid behaviour could not be observed for that run.
- Condensation formed inside the glovebox on a later flight, making the fluid hard to see.

## Safety notes

All fluid handling was confined to the glovebox; the experiment was to stop immediately on any leakage, with affected components sealed. Mechanisms were not to be forced; if a component failed, the operator was to stop and proceed to the next step.

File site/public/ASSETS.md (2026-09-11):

# Site assets

Everything here is committed and served directly. Renders and models are
regenerated by scripts in `tools/`; photographs are supplied.

## renders/ and models/, regenerated by `tools/render_parts.py`

`renders/*.png` are poster images shown on the page; `models/*.glb` are
glTF binaries for the click-to-open 3D viewer, exported from the same
Blender scene as the matching render, so each part is the same colour and
the same shape in both. Each `.glb` pairs with the render of the same
name. These are fetched only when a reader clicks a render, never on page
load, and so do not affect how fast the page opens.

| Scene | Triangles | Size |
|---|---|---|
| `concept-balloon` | 17 k | 0.4 MB |
| `concept-drawstring` | 13 k | 0.3 MB |
| `concept-duckbill` | 16 k | 0.3 MB |
| `concept-extraction-valve` | 16 k | 0.3 MB |
| `concept-flower-high` | 16 k | 0.3 MB |
| `concept-flower-low` | 38 k | 0.7 MB |
| `concept-twister` | 24 k | 0.5 MB |
| `concept-umbrella` | 26 k | 0.5 MB |
| `flower-sections` | 60 k | 1.6 MB |
| `flower-low-vs-high` | 100 k | 2.0 MB |
| `flower-low-mould` | 116 k | 2.2 MB |
| `rig-artificial-vagina` | 8 k | 0.1 MB |

The purple balloon in `concept-balloon` has no part file: `render_parts.py`
derives it as the cavity of `hardware/balloon/step/balloon-top-mould.step`,
cut flat where the vent and core-pin channels begin.

Triangle counts and sizes are the exported `.glb`, after the web-model
decimation `render_parts.py` applies; source CAD is far heavier (see
`tools/render_parts.py`'s size-budget comments).

## photos/

Photographs of the research prototypes, the casting process and the flight
glovebox, supplied by the authors.

| File | Shows | Source | Dimensions |
|---|---|---|---|
| `photos/flower-low.webp` | Flower Low cast in silicone, held between two fingers | supplied by the authors | 1108 × 1108 |
| `photos/flower-high.webp` | Flower High cast in silicone, petals nearer the rim | supplied by the authors | 1101 × 1102 |
| `photos/duckbill.webp` | Duckbill, seen into the opening | supplied by the authors | 1200 × 1200 |
| `photos/twister.webp` | Twister, the orange inner skin inside the cup | supplied by the authors | 1018 × 1018 |
| `photos/drawstring.webp` | Drawstring, test fluid leaking past the lid | supplied by the authors | 1100 × 1101 |
| `photos/umbrella.webp` | Umbrella, the orange umbrella and green frame inside the opening | supplied by the authors | 1056 × 1055 |
| `photos/mould-clamped.webp` | a printed mould clamped shut for casting | supplied by the authors | 900 × 900 |
| `photos/degassing.webp` | degassing mixed silicone in a vacuum desiccator | supplied by the authors | 1001 × 1000 |
| `photos/degassing-closeup.webp` | mixed silicone foaming under vacuum, close up | supplied by the authors | 1500 × 1500 |
| `photos/flower-low-demoulding.webp` | Flower Low during demoulding, petals and strings cast straight along the mould core | supplied by the authors | 1449 × 1449 |
| `photos/duckbill-half-in-mould.webp` | one Duckbill half in its open mould | supplied by the authors | 905 × 905 |
| `photos/drawstring-lid-mould.webp` | the Drawstring lid mould halves, one holding the cast string; frayed silicone that tore free during demoulding is stuck above each cavity | supplied by the authors | 748 × 839 |
| `photos/glovebox.webp` | the flight glovebox, with artificial vaginas, syringes, tampons and SpaceCups in labelled bags | supplied by the authors | 1600 × 1200 |
| `photos/artificial-vagina-demoulding.webp` | the self-made artificial vagina during demoulding, on its printed core with the outer mould halves opened | supplied by the authors | 1430 × 1430 |

Conversion: each source photo was EXIF-transposed to its displayed
orientation, then saved as WebP at quality 82, long edge capped at 1800 px,
with no EXIF, ICC or XMP metadata.

## Photo rules

WebP at quality 82 and at most 1800 px wide. No people's faces or names
without consent. Add the file and swap its `src`; nothing else changes.

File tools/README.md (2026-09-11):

# tools

Every derived artifact in this repository regenerates from these scripts.
No figure is a one-off screenshot.

| Script | Regenerates |
|---|---|
| `stl_units.py` | STL geometry primitives (library) |
| `verify_units.py` | CI gate, fails if any STL is not in millimetres |
| `verify_scope.py` | CI gate, fails if a tracked file is out of scope (thesis, questionnaires, training slides, NX/STEP translation logs, native NX part files, planning content, intermediate meshes, raw video, certification artwork the project is not entitled to) |
| `verify_copy.py` | CI gate, fails if banned certification/safety phrasing reaches the docs or the built site |
| `verify_privacy.py` | CI gate, fails if participant names, personal paths or email addresses reach the docs or the built site |
| `rename.py` | The old-to-new file-name mapping in [`../hardware/README.md`](../hardware/README.md#rename-map) (library) |
| `step_to_mesh.py` | Meshes converted from the STEP files, input to `render_parts.py` |
| `parts.py` | Scene manifest: which meshed solids make up each render, their role (colour), orientation and mirroring; read by `render_parts.py`, and by `tools/tests/test_parts.py`, which checks orientation against `build/meshes/` (library) |
| `render_parts.py` | `site/public/renders/*.png` and `site/public/models/*.glb` (requires Blender) |

## CI

```bash
pip install -r requirements.txt
python3 -m pytest tools/tests -v
```

## Renders

Rendering is not run in CI; it is a local, one-off step whenever the STEP files change.

```bash
python3 -m venv .venv
.venv/bin/pip install -r requirements-render.txt
.venv/bin/python tools/step_to_mesh.py
blender --background --python tools/render_parts.py
```

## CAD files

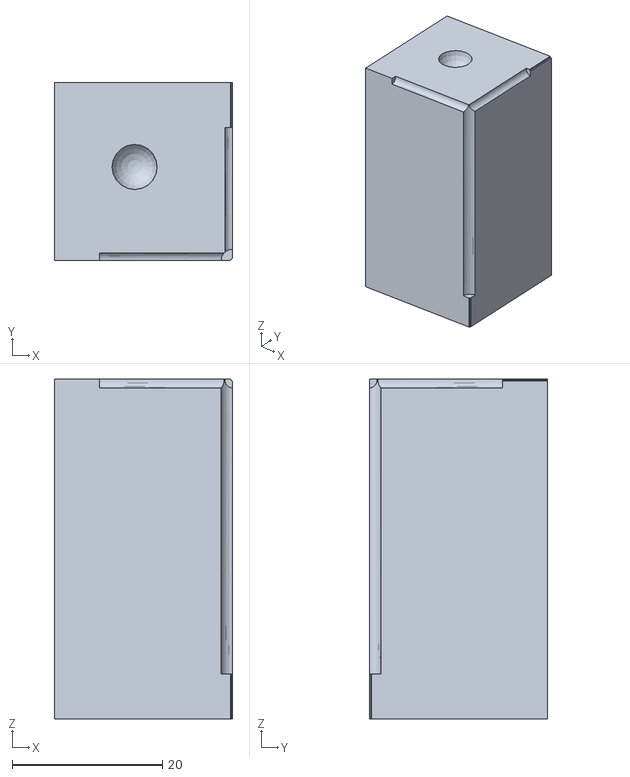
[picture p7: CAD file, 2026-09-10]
hardware/umbrella/mould-stl/umbrella-top-2-open-full-mould-u1.stl
23.7 x 23.7 x 45.2

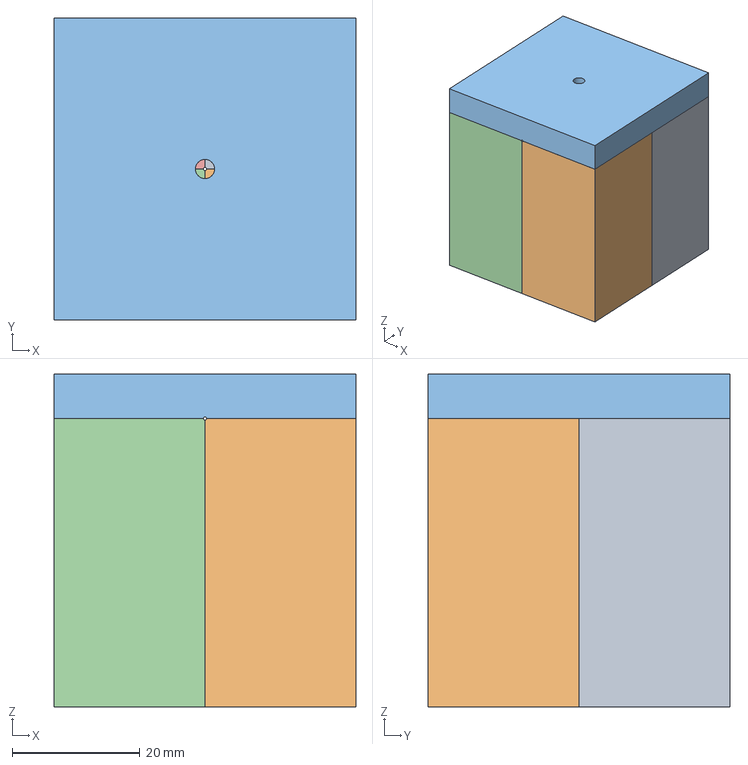
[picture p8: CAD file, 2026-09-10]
hardware/umbrella/step/umbrella-top-open-full-mould.step
47.3 x 47.3 x 52.2 mm

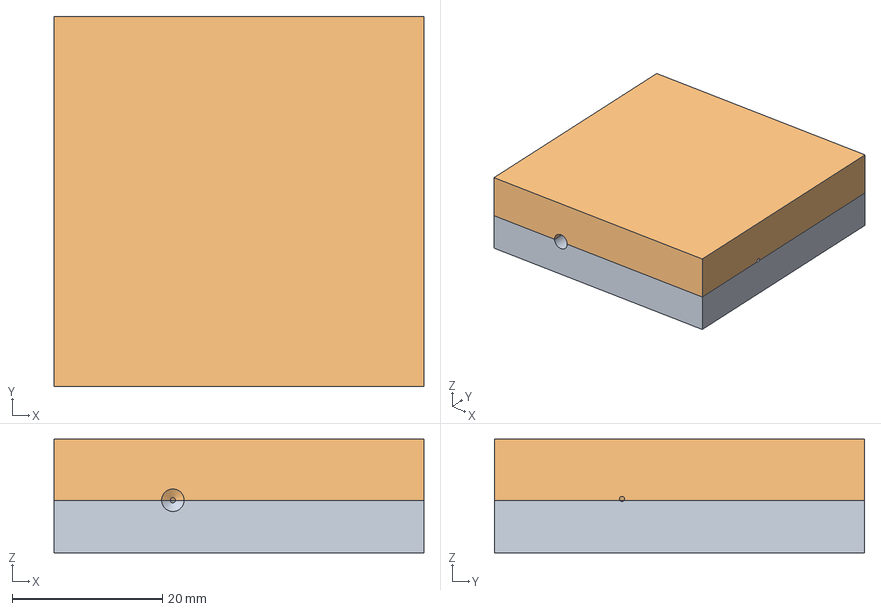
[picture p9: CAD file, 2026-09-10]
hardware/umbrella/step/umbrella-top-open-full-wings-mould.step
49.3 x 49.3 x 15.2 mm

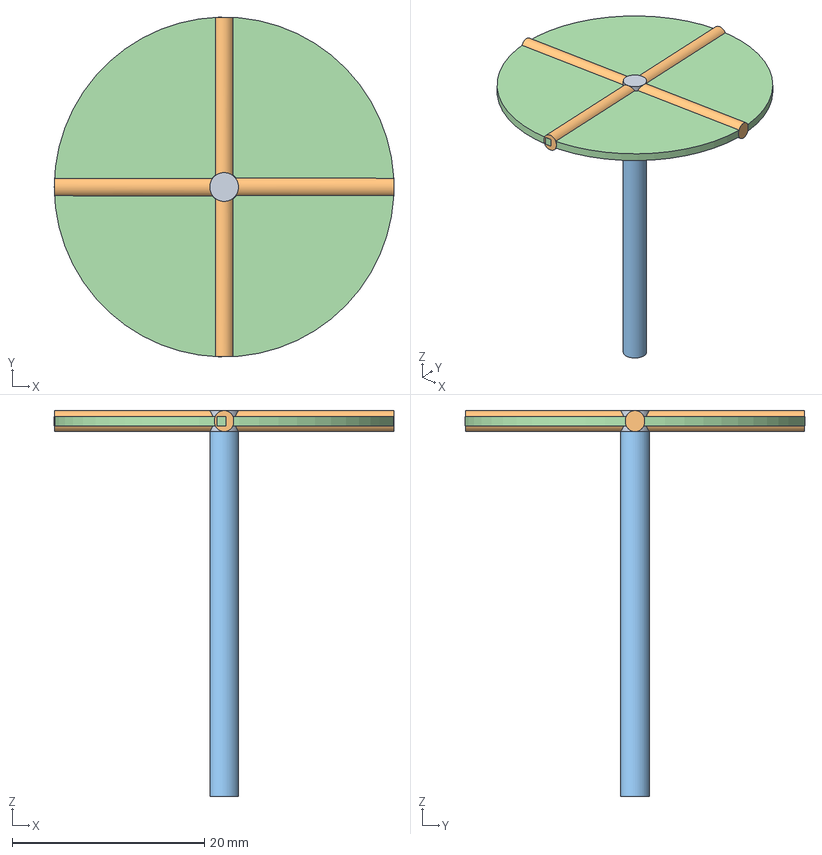
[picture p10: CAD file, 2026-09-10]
hardware/umbrella/step/umbrella-top-open-full.step
35.4 x 35.4 x 40.2 mm

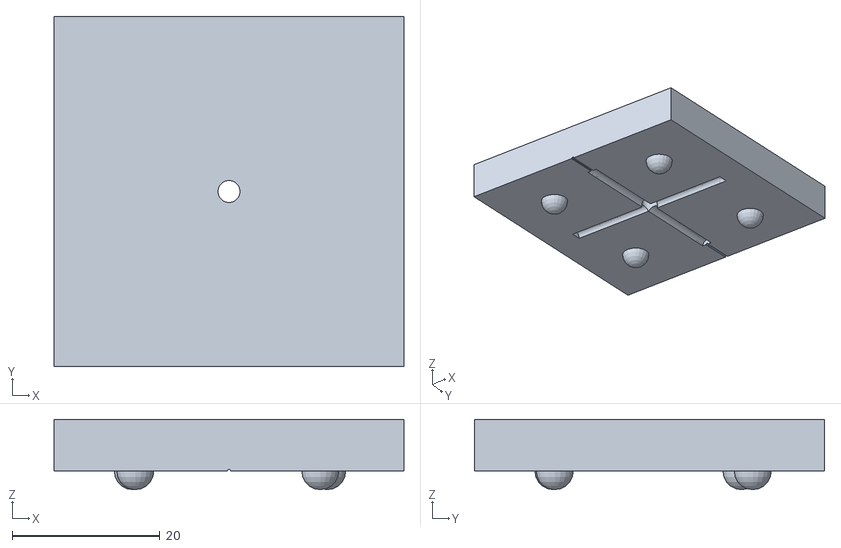
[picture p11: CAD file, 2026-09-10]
hardware/umbrella/mould-stl/umbrella-top-2-open-full-mould-top.stl
47.3 x 47.3 x 9.50

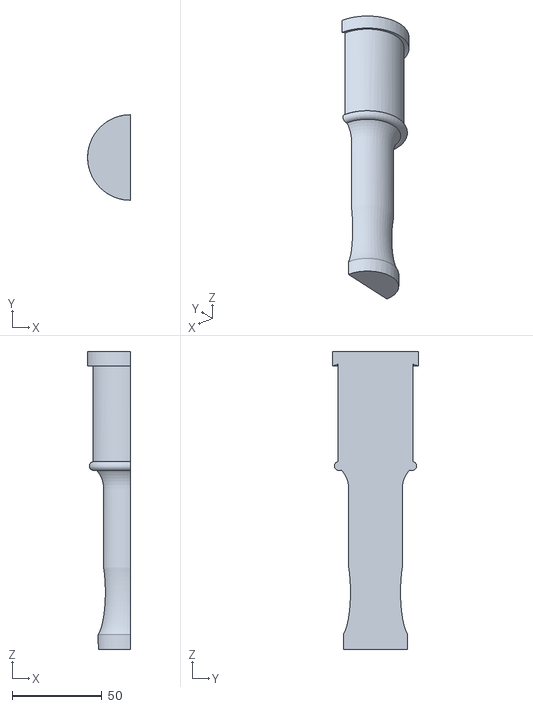
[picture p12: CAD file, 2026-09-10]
hardware/artificial-vagina/mould-stl/parabolicflight-vagina2-inleft.stl
23.9 x 47.8 x 166.4

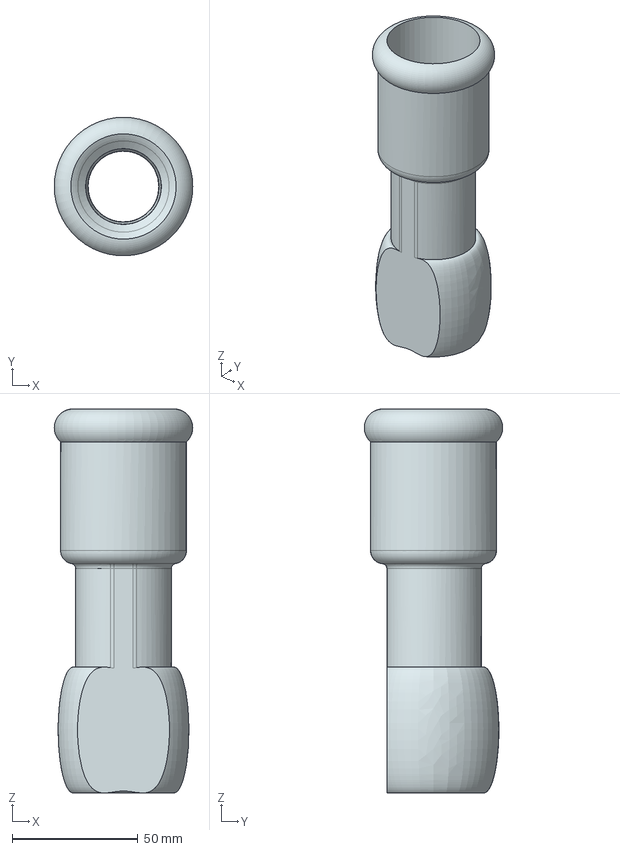
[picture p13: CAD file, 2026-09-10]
hardware/artificial-vagina/step/parabolicflight-vagina.step
55.0 x 55.0 x 152.4 mm

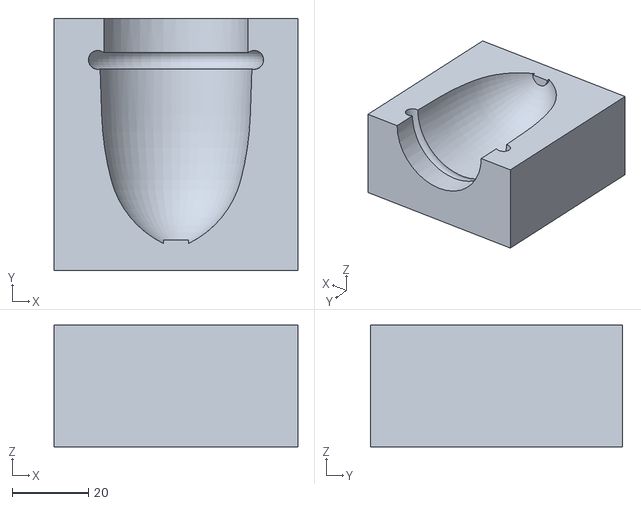
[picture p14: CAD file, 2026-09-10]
hardware/balloon/mould-stl/menstrual-cup-medium-without-balloon-mould-outsideleft.stl
64.0 x 66.0 x 32.0

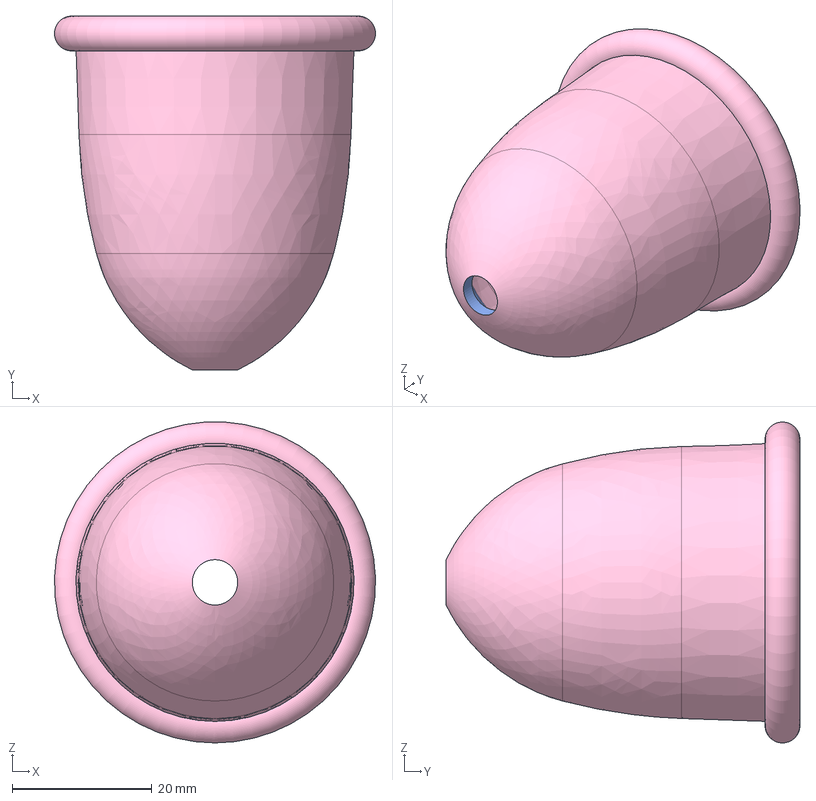
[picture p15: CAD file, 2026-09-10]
hardware/balloon/step/menstrual-cup-medium-without-balloon.step
46.0 x 50.7 x 46.0 mm

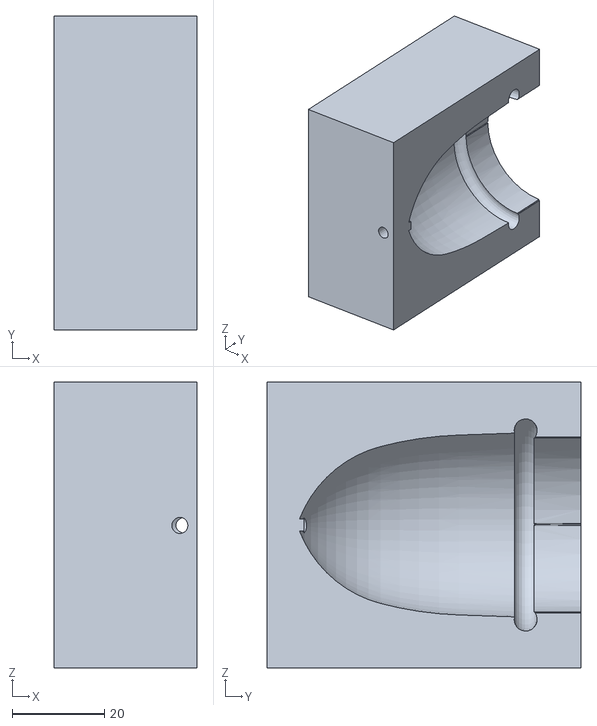
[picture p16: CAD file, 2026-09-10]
hardware/drawstring/mould-stl/menstrual-cup-medium-drawstring5-outleft.stl
31.0 x 68.0 x 62.0

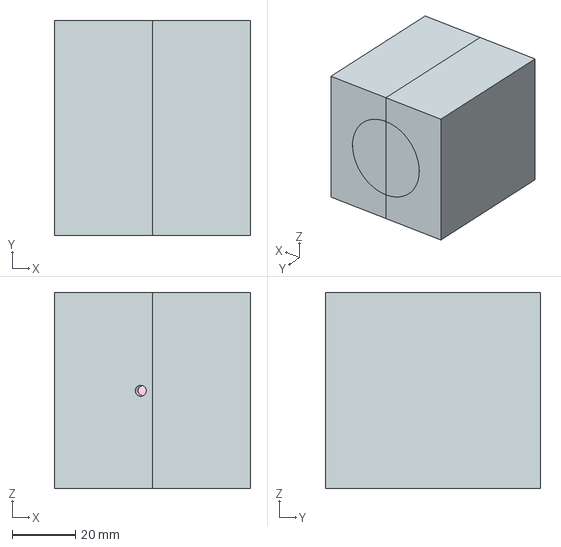
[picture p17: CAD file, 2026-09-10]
hardware/drawstring/step/menstrual-cup-medium-drawstring-mould.step
62.0 x 68.0 x 62.0 mm

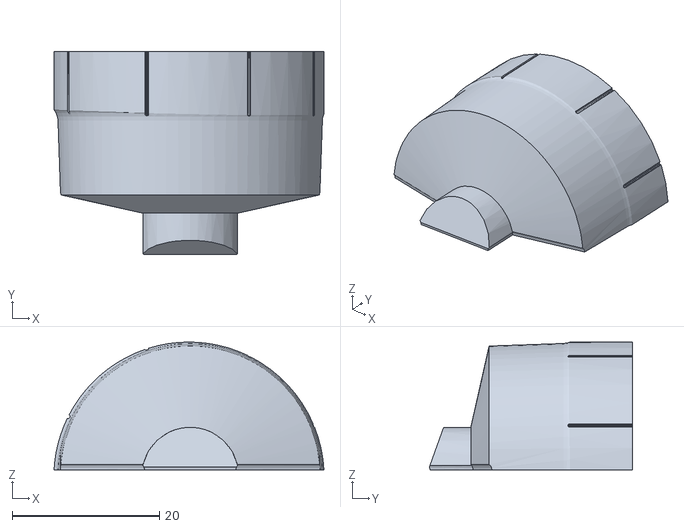
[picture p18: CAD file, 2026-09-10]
hardware/duckbill/mould-stl/duckbill2-half-withrim-insidetop.stl
36.7 x 27.6 x 17.4

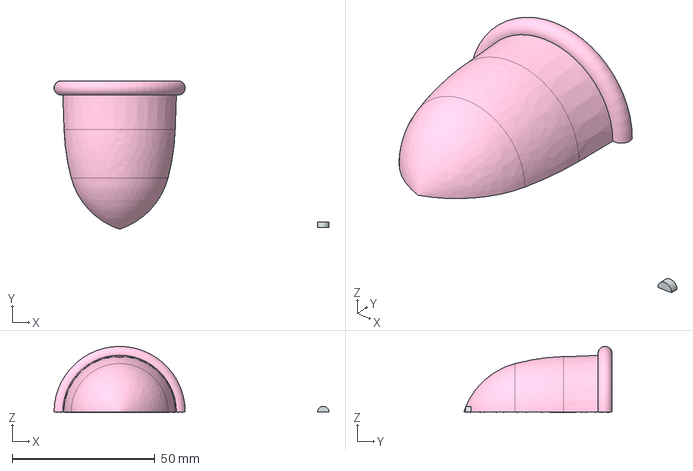
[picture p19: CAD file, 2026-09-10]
hardware/duckbill/step/duckbill-half-withrim.step
96.4 x 52.0 x 23.2 mm

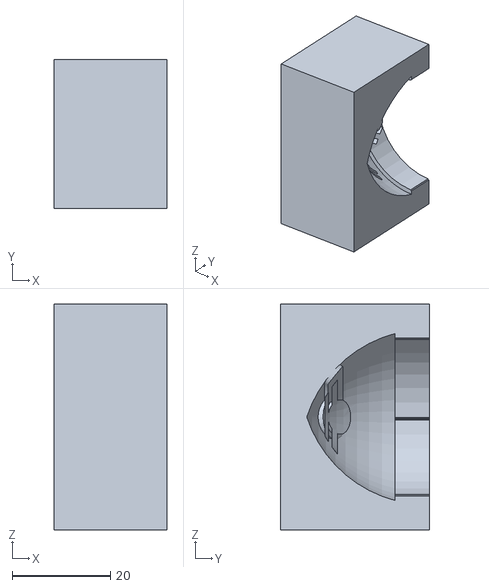
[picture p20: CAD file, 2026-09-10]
hardware/extraction-valve/mould-stl/menstrual-cup-valve-outright.stl
23.0 x 30.3 x 46.0

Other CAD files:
hardware/umbrella/mould-stl/umbrella-top-2-open-full-mould-u3.stl
hardware/umbrella/mould-stl/umbrella-top-2-open-full-mould-u2.stl
hardware/umbrella/mould-stl/umbrella-top-2-open-full-mould-u4.stl
hardware/extraction-valve/step/cup-valve-button-mould.step
hardware/artificial-vagina/mould-stl/parabolicflight-vagina2-inright.stl
hardware/artificial-vagina/mould-stl/parabolicflight-vagina2-outsideleft.stl
hardware/artificial-vagina/mould-stl/parabolicflight-vagina2-outsideright.stl
hardware/artificial-vagina/step/parabolicflight-vagina-mould.step
hardware/artificial-vagina/stl/parabolicflight-vagina-mould.stl
hardware/artificial-vagina/stl/parabolicflight-vagina.stl
hardware/balloon/mould-stl/balloon-pipe1-mould-inside.stl
hardware/balloon/mould-stl/balloon-pipe1-mould-outsideleft.stl
hardware/balloon/mould-stl/balloon-pipe1-mould-outsideright.stl
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

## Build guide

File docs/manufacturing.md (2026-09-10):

# Manufacturing

How the SpaceCup prototypes were cast, rewritten from the author's injection-moulding guide (`Injection_moulding_guide_AMMITY_KimKeller.pdf`, shipped as [`moulding-guide.pdf`](moulding-guide.pdf)) and from Keller, K. (2026). *AMMITY*. MSc thesis, ETH Zurich, Global Health Engineering. Not published with this repository, thesis pp.11-13 and p.25. This is a laboratory casting process, not the precision-machined, cleanroom moulding a commercial medical device would use.

## Printing the mould

Mould halves are 3D-printed, not machined. Material choice depends on the cure the mould has to survive:

| Cure | Suitable filament |
|---|---|
| Room-temperature cure (Smooth-Sil, Rebound) | PLA, PETG or ABS |
| Heated, 100 °C cure (medical-grade ELASTOSIL) | ASA, to resist thermal deformation at that temperature |

Print settings: 15 % infill, 0.15 to 0.2 mm layer height, 5 wall lines (moulding guide, section B).

## Mould features

- Parting line on the cup's symmetry plane, typically a vertical split.
- A short sprue or funnel at the cup stem, used as the silicone injection channel.
- 2 to 3 vent holes, about 0.5 mm in diameter, near the rim or wherever air is likely to be trapped.
- 3 mm hemispherical alignment keys, to position the mould halves accurately.
- Complex geometries may need additional mould separations to ease demoulding; every internal mould component must be secured against displacement during casting (moulding guide, section A; thesis p.11).

## Silicones used

| Silicone | Role |
|---|---|
| Smooth-Sil 945 | Main cup body |
| Rebound 25 | Flexible components |
| Smooth-Sil 960 | Rigid structural elements |
| ELASTOSIL LR 5040/45 | Medical-grade final prototype, Shore A approximately 45 |

(thesis p.11, p.12)

## Mixing and degassing

Determine the Part A to Part B mixing ratio from the silicone manufacturer's technical data sheet; the ratio varies between materials and must not be assumed to be 1:1. Mix slowly to avoid incorporating air, then transfer to a vacuum chamber and degas until the bubbles have collapsed. Complete mixing, degassing and casting within the silicone's pot life (moulding guide, section D; thesis p.11).

## Injection by syringe

The degassed silicone is transferred to a syringe, about 20 to 50 mL depending on the required volume, and injected slowly and continuously into the sprue, filling the cavity from the injection point toward the vents. Silicone appearing at a vent indicates that region has filled and displaced its air (moulding guide, section E; thesis p.11).

## Curing

| Silicone | Curing time and temperature |
|---|---|
| Smooth-Sil 945 | 6 h |
| ELASTOSIL LR 5040/45 | Manufacturer's rating: 15 min at 165 °C, for a heated industrial mould. The lab used 3D-printed ASA moulds limited to about 100 °C, and found about 2 h at 100 °C sufficient by trial and error |

(thesis p.11, p.12)

## Mixed hardness by cut-and-refill

To combine silicones of different hardness in one SpaceCup, the whole cup was first cast in one silicone. After initial curing, the mould was opened, the sections meant to have a different hardness were cut out, and fresh silicone of the desired hardness was introduced into the resulting cavities before closing the mould again to cure and bond the new material to the existing part (thesis p.12).

## Demoulding

Let the mould and silicone cool before handling, remove the clamps, and separate the mould components carefully. Demould gradually, with particular attention to thin membranes and strings, then remove excess silicone from the sprue, vents and parting lines, and inspect for trapped air, incomplete filling, tears, surface defects and dimensional inconsistencies (moulding guide, section F).

## Epoxy mould coating

A thin epoxy coating can seal microcracks and layer lines in the printed mould cavity, giving a smoother silicone surface, but it needs about 48 h to cure. Because of that curing time, this step was mostly skipped in prototyping (thesis p.11).

## Known defects

From Fig. 9 (thesis p.25): air entrapment during the transfer of silicone from the mixing plate to the injection syringe, demoulding tears from complex enclosed geometries, layer lines and surface irregularities transferred from the 3D-printed mould, and fragile, thin membrane structures (notably the Balloon) that were highly sensitive to material distribution and mould alignment.

The medical-grade ELASTOSIL silicone was too viscous to inject with the syringe setup; it was instead spread by hand directly onto the mould surfaces before the mould halves were clamped together, which limited how completely trapped air could be removed and left more air bubbles in the cured part (thesis p.25).

## Disclaimer

The use of medical-grade silicone does not make the resulting prototype a certified medical device. Medical-device production would require additional controls, validated manufacturing processes, biocompatibility assessment, and appropriate quality-management documentation. The SpaceCup is a research prototype, manufactured in a standard laboratory environment, not a certified medical device.

## Full guide

The full moulding guide is shipped as [`moulding-guide.pdf`](moulding-guide.pdf).

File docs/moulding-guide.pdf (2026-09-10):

### Injection Moulding Guide

A. Mould Geometry
- Design a two-part mould, split along the cup’s symmetry plane, typically in a vertical orientation.
- Include a short sprue or funnel at the cup stem to serve as the silicone injection channel.
- Add 2–3 small vent holes (approximately 0.5 mm in diameter) near the rim or other locations where air is likely to become trapped.
- Incorporate alignment keys, such as 3 mm hemispherical features, to ensure accurate positioning of the mould halves.
- For complex geometries, consider additional mould separations to facilitate demoulding. Ensure that all internal mould components can be securely fixed to prevent displacement during casting.
B. Material Selection and 3D Printing
- Select a filament with sufficient dimensional stability and temperature resistance for the intended curing process. PLA, PETG, ABS, or ASA may be suitable for laboratory moulds, depending on the required temperature.
- Infill: 15%
- Layer height: 0.15–0.2 mm.
- Wall lines: 5.

Surface finishing

1. Sand the mould cavity to reduce visible layer lines and surface irregularities, using progressively finer abrasive paper where accessible.
2. If required, apply a thin, compatible epoxy coating to seal the printed surface and improve smoothness.
3. Allow the coating to cure fully according to the manufacturer’s instructions before casting.
4. Inspect the cavity for coating defects, blocked vents, or dimensional changes.

Surface finishing can reduce the transfer of printing texture to the silicone and improve the quality of the final prototype.

C. Mould Preparation
1. Clean the mould halves thoroughly with soap.
2. Rinse and dry the mould completely, ensuring that no cleaning residues remain.
3. Assemble the mould and secure all internal components.
4. Clamp the mould halves using bolts, a clamp frame, or another suitable fixture.
5. Check that the parting line is properly closed and that the sprue and vent channels remain unobstructed.

D. Silicone Mixing and Degassing
1. Determine the correct mixing ratio from the silicone manufacturer’s technical data sheet. The ratio may vary between materials and must not be assumed to be 1:1.
2. Prepare the required quantities of Parts A and B.
3. Mix the components slowly and thoroughly, avoiding unnecessary air incorporation.
4. Transfer the mixture to a suitable vacuum container and degas until all bubbles collapsed.
5. Complete mixing, degassing, and casting within the specified pot life.
E. Casting and Manual Injection

General-purpose prototyping silicone

1. Transfer the degassed silicone into a suitable syringe (approximately 20–50 mL, depending on the required volume).
2. Minimize air entrapment during transfer by maintaining a continuous flow and avoiding repeated pouring.
3. Insert the syringe tip into the sprue.
4. Inject the silicone slowly and continuously, allowing the cavity to fill from the injection point toward the vents.
5. Observe the vent openings. The appearance of silicone indicates that the corresponding regions have filled and air has been displaced.
6. If necessary, close the vents using a suitable method (tape or wax) that does not introduce contamination or disturb the mould.
7. Maintain the mould in the required orientation, close the sprue tunnel with a paper towel piece and cure the silicone according to the manufacturer’s specified conditions.

Medical-grade silicone (ELASTOSIL® LR 5040/45)

Due to its higher viscosity, the medical-grade silicone used in this thesis could not be injected successfully using the available syringe setup. Instead, the silicone was distributed directly onto the mould surfaces before the mould halves were assembled and clamped.

The manufacturer specifies curing conditions for heated industrial moulds. For the laboratory process used in this thesis, the curing temperature was limited to 100 °C to avoid deformation of the 3D-printed moulds (use ASA). A curing time of approximately 2 hours at 100 °C was established experimentally for this specific setup.

These conditions should be regarded as laboratory-specific and should be verified for any changes in mould material, geometry, silicone batch, or processing equipment.

F. Demoulding and Inspection
1. Allow the mould and silicone to cool sufficiently before handling.
2. Remove the clamps and separate the mould components carefully.
3. Demould the silicone part gradually, paying particular attention to thin membranes, strings, and enclosed features.
4. Remove excess silicone from the sprue, vents, and parting lines.

5. Inspect the prototype for trapped air, incomplete filling, tears, surface defects, and dimensional inconsistencies.
6. Record any manufacturing defects and their likely causes to support further mould and process optimization.

Note: This procedure describes laboratory prototype manufacturing. The use of medical-grade silicone alone does not make the resulting prototype a certified medical device. Medical-device production would require additional controls, validated manufacturing processes, biocompatibility assessment, and appropriate quality-management documentation.

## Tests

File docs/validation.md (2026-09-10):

# Validation

What the SpaceCup prototypes were tested against, at 1 G on the bench and in reduced gravity in flight, and what remains untested. Sourced from Keller, K. (2026). *AMMITY*. MSc thesis, ETH Zurich, Global Health Engineering. Not published with this repository, and from [`../data/`](../data/README.md).

## Bench tests at 1 G

Six mechanisms (the balloon excluded, not reliably manufacturable, see [`design.md`](design.md)) were evaluated under standard laboratory conditions, using a self-made anatomical vaginal model, injection-moulded from a soft silicone in a printed mould (thesis p.14).

**Fluid recipe:** egg white 30 mL, ketchup 50 mL, sucrose solution (30 % sugar in water) 20 mL. Ketchup gives base viscosity and shear-thinning behaviour, egg white simulates clot-like structures, and the sucrose solution adjusts density (thesis p.15).

**Sealing performance and fluid containment:** each cup was filled with the artificial fluid to capacity, inverted, and visually inspected for leakage at the rim and the sealing mechanism (thesis p.15). The target containment volume was 12 mL, based on the average menstrual fluid volume collected over an 8-hour period, reported in the literature as approximately 2 to 12 mL (thesis p.15, citing Hallberg et al., 1966).

**Structural reliability:** each mechanism was activated repeatedly, 30 cycles, with varying applied force (thesis p.15).

**Usability cycle:** insert the prototype into the vaginal model, fill with artificial fluid, extract, remove the fluid with a syringe, clean the cup, and reset the closing mechanism for the next cycle (thesis p.15).

Each criterion was scored 1 (not met) to 5 (fully met) against the definitions in Table 1 (thesis p.16); see [`design.md`](design.md) for the full scale and the score table from [`../data/ground-test-scores.csv`](../data/ground-test-scores.csv). Both Flower designs scored highest, 24/25.

## Parabolic flight

Reduced-gravity testing was conducted during the Asclepios VI parabolic-flight campaign; see [`flight-protocol.md`](flight-protocol.md) for the full protocol. Only the Flower Low mechanism was flown, because it was the only fully functional prototype available at the time of the campaign (thesis p.17).

The results are qualitative: no fluid volumes were measured in flight (thesis p.22; [`../data/README.md`](../data/README.md)). Summarised from [`../data/flight-questionnaire.csv`](../data/flight-questionnaire.csv) (3 participants):

- 2 of 3 participants reported minor leakage on containment; the third (P2) could not observe containment or fluid behaviour, because the artificial vagina leaked before the parabola began.
- All 3 participants rated activation of the sealing mechanism easy or very easy.
- 2 of 3 rated insertion easy, and 1 rated it moderate; 2 of 3 rated extraction very easy, and 1 rated it easy.
- All 3 reported the procedure felt safe and well controlled.
- 2 of 3 (the ones who could observe it) reported the fluid mostly stable in reduced gravity.

Limitations, from the thesis's own discussion of the flight results (thesis p.22):

- The available reduced-gravity time per parabola was too short for a detailed characterisation of fluid behaviour.
- The small test-fluid volume made fluid movement hard to visualise and prevented a reliable quantitative comparison of containment between the SpaceCup and the tampon.
- The artificial vagina's limited transparency and simplified geometry restricted direct observation of the interaction between fluid, vaginal walls and the SpaceCup.
- Each parabola's short window provided only a limited observation period and did not represent the conditions of wearing a cup for an extended period in continuous microgravity.

## Cleaning

The cleaning assessment (thesis p.23) is summarised in [`use.md`](use.md#cleaning), with colony counts in [`../data/cleaning-colony-counts.csv`](../data/cleaning-colony-counts.csv).

## What is not established

The testing performed does not establish: long-duration wear (all tests were single activation-and-removal cycles, not extended wear), performance under continuous microgravity (parabolic flight gives only short, repeated windows of reduced gravity, not sustained microgravity), or quantitative containment (the flight tests produced qualitative observations, with no measured fluid volumes; thesis p.22).

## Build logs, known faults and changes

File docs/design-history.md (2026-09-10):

# Design history

Where the SpaceCup's base geometry came from, the concept path from seven mechanisms to a single flown prototype, and the future work the thesis recommends. Sourced from Keller, K. (2026). *AMMITY*. MSc thesis, ETH Zurich, Global Health Engineering. Not published with this repository.

## The base cup

The base cup's geometry, wall thickness, stem length, rim diameter, length and capture volume (see [`design.md`](design.md)) were defined by a 2025 BSc thesis of the same title, by S. Pfeiffer, at ETH Zurich (thesis p.9, p.31). That thesis is unpublished and is cited here only; it is not part of this repository.

## Earlier internal work

Dugué, M. (2024). *Menstrual blood collection in micro-gravity: Parabolic flight results* [Internal document]. This internal document supplied the ingredient selection behind the artificial menstrual fluid recipe used throughout bench and flight testing (thesis p.15); it is not part of this repository.

## The concept path

Seven mechanisms were designed on the shared base cup: Flower Low, Flower High, Twister, Umbrella, Balloon, Duckbill and Drawstring (thesis p.9). All but Balloon, which could not be manufactured reliably, went through the functional bench-test scoring described in [`design.md`](design.md). Of those, only Flower Low was carried forward to reduced-gravity flight testing, as the only fully functional prototype available at the time of the parabolic-flight campaign (thesis p.17); see [`validation.md`](validation.md) and [`flight-protocol.md`](flight-protocol.md). The extraction valve, in [`../hardware/extraction-valve/`](../hardware/extraction-valve/), sits outside this path: it is an early, untested take on one of the alternative collection principles the thesis recommends for future comparison, described below.

## Future work

From the thesis's discussion and conclusions (thesis pp.26-30):

- Simplify the Flower mechanism, with particular emphasis on cleanability, manufacturability, and operation with medical-grade silicone.
- Run longer, more representative reduced-gravity tests, using the more transparent, anatomically representative artificial vagina model developed in this thesis (see [`../hardware/artificial-vagina/`](../hardware/artificial-vagina/)).
- Before further optimising a cup geometry, first study how menstrual-like fluid is transported and distributed within the vagina during prolonged reduced gravity, since the current concept assumes the fluid reaches the cup in a predictable way, which is not yet established.
- Compare the SpaceCup approach against fundamentally different collection principles: a reusable sponge-like absorbent system, a suction-based system, and a cup with a syringe or extraction port that lets fluid be removed while the cup stays inserted. The extraction-valve files in this repository are an early, untested take on the last of these.
- For cleaning, try combining shaking with microwave treatment: placing the cup in a closed container with a small amount of water, shaking it, then microwaving, to loosen trapped residue before heating.
- For manufacturing, sand the mould cavities to reduce transferred layer lines, and avoid very thin features, which were more prone to manufacturing defects and damage.

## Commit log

2026-09-10 chore: scaffold licences, requirements and the STL-units gate
    Claude-Session: https://claude.ai/code/session_01LYtPEvf5VAbupfcYfzzeMk
2026-09-10 hardware: import the nine variants (NX, STEP, mould STL) under the naming rule
    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
    [Balloon_Top_mold.prt, Drawsting.prt, Drawsting_mold.prt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]
2026-09-10 tools: mesh STEP solids to per-solid STL for the renders
    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
2026-09-10 parts: correct flower-low captions, lower default render resolution
    The renders show the flower-low pull-strings extending up out of the
    rim opening, not down through a stem as the old captions claimed
    (measured: string solid spans old-Y 13.4-112.4mm, entirely above the
    petal base, while the cup's bottom nub sits at old-Y around -23mm) so
    both the concept and section captions are corrected to describe what
    is actually shown.
    Also drops the Scene resolution default from 1000 to 800, the
    controller-authorized first lever for the 20 MB renders+models budget
    (tools/render_parts.py separately tightens the web-model triangle
    ceiling for the same reason; see its comment).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
2026-09-10 renders fix round 1: correct flower-low captions, tame section lighting, cut open drawstring
    Review findings, controller-ruled:
    1. Flower Low captions said the strings were "through the stem"; per
    thesis p.10 each petal is joined to the pull mechanism in the stem by
    a flexible silicone string, and the renders show them straight, as
    cast (not pulled). Corrected CONCEPT_CAPTIONS["flower-low"] and the
    flower-low-section Scene caption in tools/parts.py; the flower-low
    Scene caption is unchanged.
    2. flower-low-section.png was washed out: the section layout's cut-fill
    light (added so the cut face isn't a dark band) was also flooding the
    already-lit outer wall and mechanism,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
2026-09-10 renders fix round 2: drop drawstring section cut, add per-scene camera view
    Re-review found two open issues in concept-drawstring, both controller-ruled:
    (a) Fix round 1's layout="section" cut left a sharp-edged near-black
    patch (~3,400 opaque pixels, not the single pixel my report
    described) in the lower left, most likely inside-out faces from
    cut_half's boolean on solid 0.
    (b) Even cut open, the mechanism wasn't legible: the grey V-shaped
    rails are solid 0 (body), confirmed via the glTF materials and
    bounding boxes; the six mechanism solids are small and sit next to
    the rim, so "cut away to show the channels" overclaimed what the
    image showed.
    Reverted concept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
2026-09-10 data: bench scores, cleaning counts and anonymised flight questionnaire
    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
    [cleaning-colony-counts.csv, codebook.csv, flight-questionnaire.csv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]
2026-09-10 site: restore the Asclepios VI campaign name from the flight material
    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
2026-09-10 docs: fix the units check command and drop an unsourced insertion claim
    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
2026-09-10 site: device, mechanisms, make, use, validation and limitations sections
    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
2026-09-10 docs: fix mechanism counts and artificial-vagina bench/flight attribution
    Consistently state seven mechanisms designed, six bench-scored (balloon
    excluded, not reliably manufacturable), only Flower Low flown, and the
    extraction valve as an eighth, later, untested concept outside the
    thesis. Fixes docs/design.md (base-geometry intro, mechanism-count
    summary, extraction-valve section), docs/validation.md (mismatched
    "seven... balloon excluded" count), and hardware/README.md
    (extraction-valve row and known-gaps note).
    Also corrects hardware/README.md's artificial-vagina row and
    docs/validation.md: the self-made model in hardware/artificial-vagina
    was used for the 1 G bench tests (thesis pp.14-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
2026-09-10 docs: fix use.md attribution, drop unsourced claims, fix Use.astro copy
    docs/use.md:
    - Delete the unsourced sentence "This is the standard technique used
    for commercial menstrual cups generally, not a SpaceCup-specific
    one." from the Insertion section.
    - The Extraction section attributed bench-testing results to
    "analogue-astronaut testers", but analogue astronauts only flew the
    parabolic flights; the bench evaluation was run in the lab (thesis
    pp.14-16, 20-21). Reworded to attribute bench results to "the bench
    evaluation" and flight results to "analogue-astronaut testers"
    separately.
    - The Resetting section claimed "bench and flight testers" reported
    the Flower's reset needi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
2026-09-10 ci: scan the whole built site for personal data, not just HTML
    The built-site privacy gate only scanned site/dist/**/*.html, so
    personal data reaching built CSS or JS (e.g. assembled via a template)
    would have shipped undetected. Scan site/dist/**/* instead;
    verify_privacy.py already filters by its own TEXT_SUFFIXES internally,
    so this is safe against binary assets. Confirmed locally after
    `npm run build`: 0 hits.
    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
2026-09-10 chore: clean up leftover template comments and stray em dashes
    Several comments were leftovers from earlier project states and no
    longer describe this codebase:
    - model-viewer.js pointed to "the CSS in Device.astro", which was
    renamed to ModelDialog.astro.
    - model-viewer.js referenced a "37 mm filter support" and a "strand
    mesh", neither of which is a SpaceCup part; reworded to neutral
    language about small parts.
    - global.css's dark-theme warning referenced site/public/figures/*.svg,
    which doesn't exist; the site ships site/public/renders/*.png.
    - render_parts.py referenced a "membrane-clamp" figure/crop/shot in
    three comments, a part from the 3DPLAM template project this code
    w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
2026-09-10 docs: correct CERN-OHL-P framing, include tooling under CC BY 4.0, clarify flight-questionnaire note
    CITATION.cff's comment called CERN-OHL-P v2 "the more restrictive" of
    the two licences; reworded to simply state it's the licence that
    governs the hardware design.
    README.md's and Footer.astro's licence tables listed the CC BY 4.0
    row as "Documentation, data and this site", omitting tooling. Per
    decision D6, tools/ is also CC BY 4.0; both rows now read
    "Documentation, data, site and tooling".
    data/flight-questionnaire.csv's P2 note ended with the ambiguous
    "(the form refers to the second flight)". Paraphrased to state plainly
    what the form says: "The form gives 18.05.2026 as the date but
    de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
    [flight-questionnaire.csv]
2026-09-11 hardware: drop the NX part files and scan binaries for local paths
    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
    [Balloon_Top_mold.prt, Drawsting.prt, Drawsting_mold.prt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]
2026-09-11 site: add photos of the prototypes, casting and the flight glovebox
    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
2026-09-11 renders: flower sections and purple mechanisms, drawstring lid
    - flower-sections (new, 2000 px): Flower Low and Flower High side by side,
    each cut through its own axis; replaces the flower-low and
    flower-low-section Device cards, scenes, renders and models.
    - flower-low-vs-high and concept-flower-high: Flower High's petals and
    strings now purple. Its STEP file is one fused solid, so tools/parts.py
    splits it by a geometric rule (FaceSplit) calibrated on Flower Low's
    separate solids; render_parts builds the rule's region as a solid and
    splits by two EXACT booleans (closed pieces, clean section caps).
    - Section layout: per-group cut, plane 0.05 mm off the parting seam
    (a cut on th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
2026-09-11 renders: derive the balloon from its mould cavity
    The balloon has no part file, only its mould. render_parts now derives
    it (Group.derive = "mould-cavity"): the joined mould pieces are
    EXACT-differenced from a box 0.2 mm inside their bounding box, the
    largest loose part is kept (asserted to be the only one over 10 % of
    the cavity volume), and it is cut flat at both ends of the run of
    cross-sections free of sliver sheets along its longest axis
    (tools.parts.clean_extent), which removes the comb slivers left in the
    vent and core-pin clearance channels. The trimmed part is checked
    closed.
    concept-balloon shows it in purple beside the cup and bulb pipe
    (flat-lay); caption, hardware/README.md and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
2026-09-11 docs: fix stale NX-files and hardware/README wording
    .zenodo.json claimed the archive ships Siemens NX native files; those
    were removed, so describe the archive by what it actually contains
    (STEP, whole-part STL and print-ready mould STL), matching
    hardware/README.md and hardware/nx.md.
    hardware/README.md: the two small flower-low solids sit at the stem
    end, not at the rim; correct the description. Also drop the stl/ vs
    Device.astro's "for viewing and CAM" vs "for viewing" mismatch so the
    folder is explained the same way in both places.
    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
2026-09-11 site: label derived and simplified renders on the mechanisms cards
    Mechanisms.astro's concept cards showed a generic alt text and used
    the mechanism name as the 3D-viewer caption, so derived or simplified
    renders (Balloon's mould-cavity balloon, Drawstring's flat lid, Flower
    High's one-solid petal colouring) were unlabelled on the site even
    though tools/parts.py's CONCEPT_CAPTIONS already describes them
    correctly. Give every card a render-specific caption (used for both
    the note and the 3D-viewer data-caption) and a render-specific alt
    text, mirroring CONCEPT_CAPTIONS in meaning so the two never disagree.
    Also:
    - Add a sentence under "The prototypes" noting that photo colour marks
    a part'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
2026-09-11 tools: fix stale scene references and cover both STL globs
    render_parts.py's usage example ran the deleted "flower-low" scene;
    use "flower-sections", which still exists. A tuning comment also cited
    a deleted flower-low.png comparison image; point it at
    flower-low-vs-high.png instead.
    verify_units.py only defaulted to checking hardware/*/mould-stl/*.stl,
    leaving the whole-part meshes under hardware/*/stl/*.stl unchecked by
    default; cover both globs in the docstring and the default argument,
    matching hardware/README.md's documented usage.
    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
2026-09-11 site: place the small Flower Low solids at the stem end
    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
2026-09-11 site: zoomable photos, bench-score links, drop section eyebrows, scope Use to the Flower designs
    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
2026-09-25 site: revise copy, reorder to mechanisms then selected prototype, pair renders with prototype photos
    Rewrites the hero, background, device and limitations copy from the author's
    review; drops the residue limitation, which describes a cleaning result rather
    than a limitation of the study. Moves the selected prototype after the closing
    mechanisms and renames its heading. Each mechanism now shows its render beside
    its cast prototype photo, so the separate prototype grid is gone.

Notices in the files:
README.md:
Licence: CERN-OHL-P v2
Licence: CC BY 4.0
